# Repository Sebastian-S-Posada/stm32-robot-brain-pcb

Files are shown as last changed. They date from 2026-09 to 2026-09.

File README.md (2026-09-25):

# STM32 Robot Brain PCB

A custom controller board for a small mobile robot, designed in KiCad. It's built around an **STM32F103RCT6** microcontroller and brings together motor drive, sensor, Bluetooth, and programming connections on one 2-layer board.

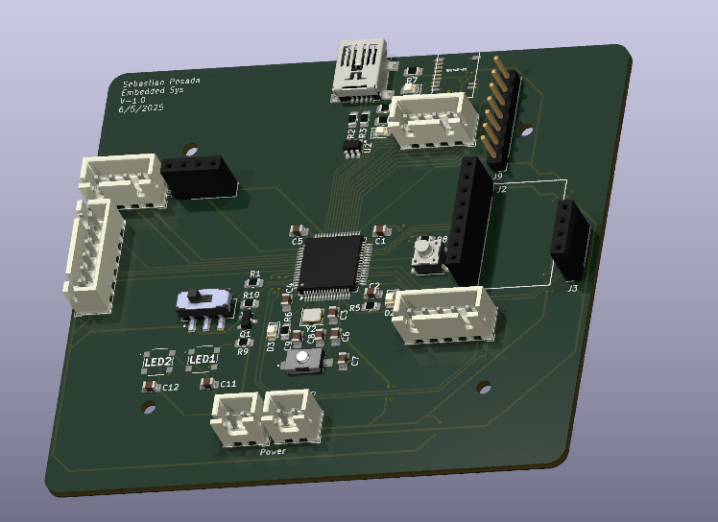
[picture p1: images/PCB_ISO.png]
3D render of the board


## Features

- **MCU:** STM32F103RCT6 (ARM Cortex-M3, LQFP-64) with a 16 MHz crystal
- **Bluetooth:** MDBT42T-AT module (nRF52-based BLE)
- **USB:** Mini-B connector with USBLC6-2SC6 ESD protection and a resettable PTC fuse
- **Programming:** SWD header, plus BOOT and RESET switches
- **Sensor headers:** MPU6050 IMU and ultrasonic distance sensor
- **Robot I/O:** motor driver, Hall-effect encoders, track sensor, PS2 controller, and UART (JST-XH connectors)
- **Power:** separate 5 V and 3.3 V inputs, with power indicator LEDs
- **User I/O:** user button, user LED, Bluetooth status LED, and two RGB LEDs
- **Level shifting:** BSS138 MOSFET

## Images

| Top | Bottom |
|---|---|
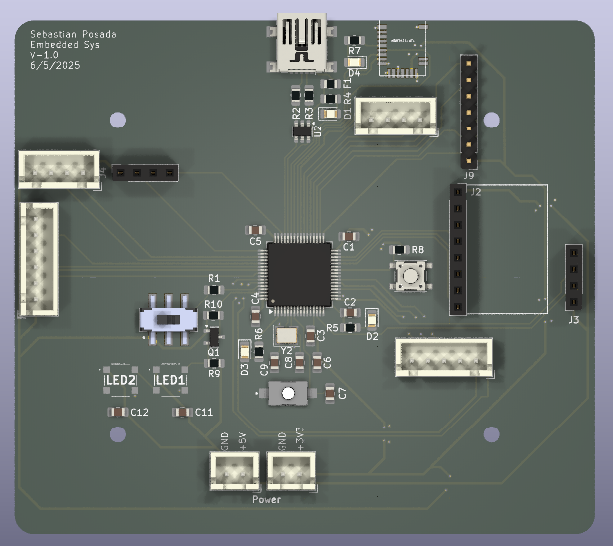
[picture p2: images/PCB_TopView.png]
Top view
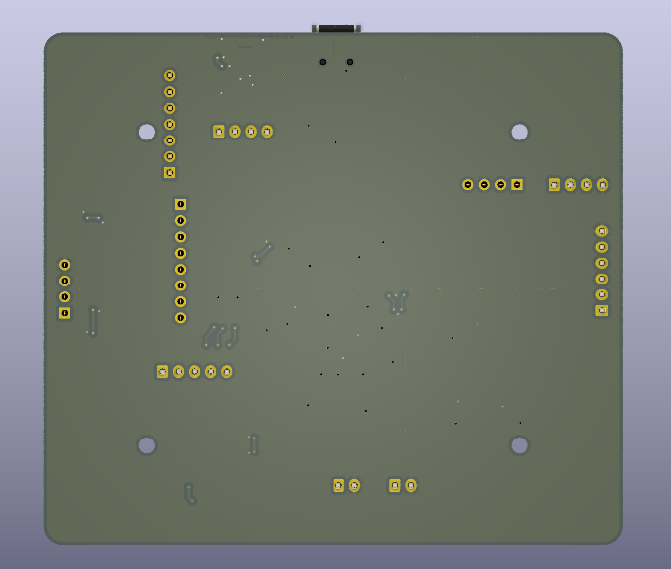
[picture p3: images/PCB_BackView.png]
Back view
|  |  |

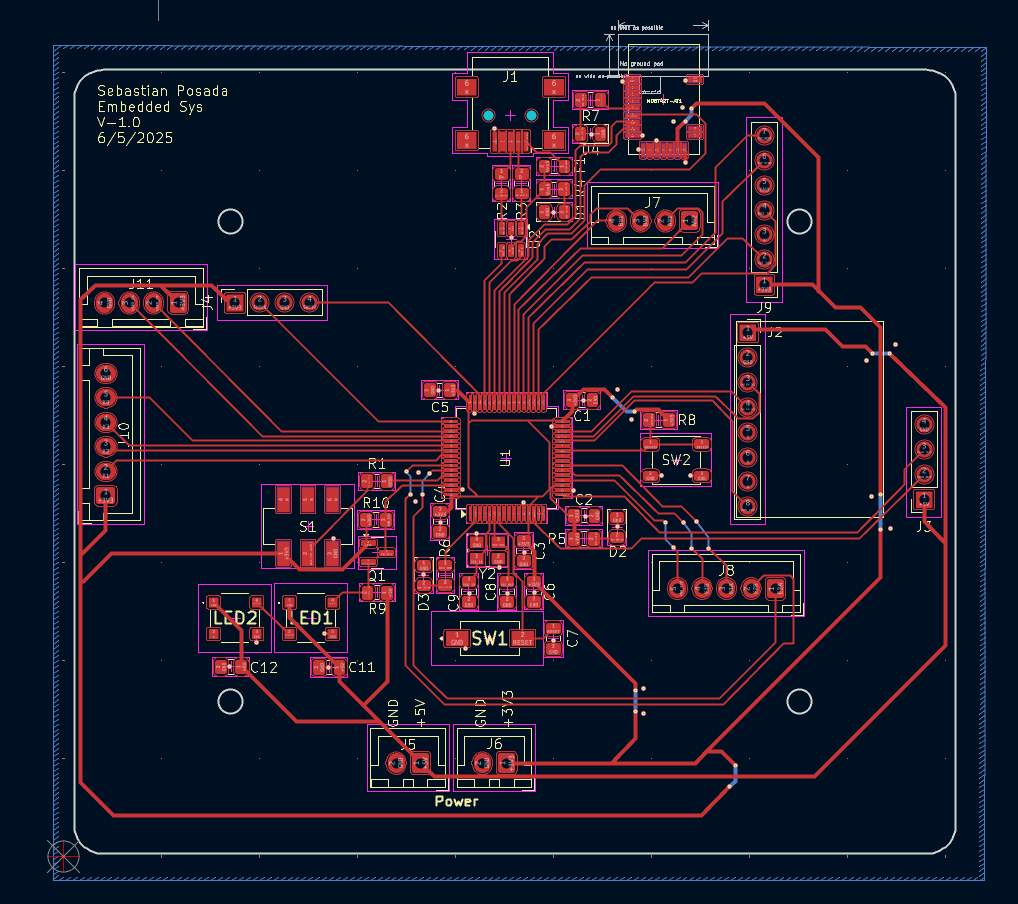
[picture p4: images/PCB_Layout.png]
Routed layout


The full schematic is in [images/schematic.pdf](images/schematic.pdf).

## Repository layout

```
hardware/
  *.kicad_pro / .kicad_sch / .kicad_pcb   KiCad project, schematic, and layout
  motor_controller.kicad_sch               Motor controller sub-sheet
  components/                              Custom symbols, footprints, and 3D models
  BOM/                                     Bill of materials (CSV)
  gerber/                                  Fabrication files (Gerbers and drill files)
images/                                    Renders and schematic PDF
```

## Opening the project

1. Install [KiCad](https://www.kicad.org/) (version 8 or newer).
2. Open `hardware/2025_04_STM32F103_RobotBrain.kicad_pro`.

To order boards, zip the contents of `hardware/gerber/` and upload them to a PCB fab such as JLCPCB or PCBWay.

## Context

Designed for an embedded systems course (ENCE 4231), spring 2025.

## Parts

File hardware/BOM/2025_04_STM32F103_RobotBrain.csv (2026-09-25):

Reference | Qty | Value | DNP | Footprint | Mfr #P | Mouser | Unit Price($)
C1,C2,C3,C4,C5,C11,C12 | 7 | 0.1uF |  | Capacitor_SMD:C_0805_2012Metric_Pad1.18x1.45mm_HandSolder | KAM21BR71H104JT | https://www.mouser.com/ProductDetail/KYOCERA-AVX/KAM21BR71H104JT | 0.20
C6 | 1 | 10uF |  | Capacitor_SMD:C_0805_2012Metric_Pad1.18x1.45mm_HandSolder | LMK212ABJ106KG-T | https://www.mouser.com/ProductDetail/TAIYO-YUDEN/LMK212ABJ106KG-T?qs=vF%252B8ahGVileYw6h2RCH8zg%3D%3D | 0.11
C7 | 1 | 0.01uF |  | Capacitor_SMD:C_0805_2012Metric_Pad1.18x1.45mm_HandSolder | KAF21BR72A103JT | https://www.mouser.com/ProductDetail/KYOCERA-AVX/KAF21BR72A103JT | 0.10
C8,C9 | 2 | 22pF |  | Capacitor_SMD:C_0805_2012Metric_Pad1.18x1.45mm_HandSolder | 0805ZA220JAT2A | https://www.mouser.com/ProductDetail/KYOCERA-AVX/0805ZA220JAT2A?qs=qVfB0%2FDaMDayn2JkoZWS9w%3D%3D | 0.21
D1 | 1 | USB_PWR_LED |  | LED_SMD:LED_0805_2012Metric_Pad1.15x1.40mm_HandSolder | 150080VS75000 | https://www.mouser.com/ProductDetail/Wurth-Elektronik/150080VS75000 | 0.19
D2 | 1 | uP_PWR_LED |  | LED_SMD:LED_0805_2012Metric_Pad1.15x1.40mm_HandSolder | 150080VS75000 | https://www.mouser.com/ProductDetail/Wurth-Elektronik/150080VS75000 | 0.19
D3 | 1 | USER_LED |  | LED_SMD:LED_0805_2012Metric_Pad1.15x1.40mm_HandSolder | 150080RS75000 | https://www.mouser.com/ProductDetail/Wurth-Elektronik/150080RS75000 | 0.19
D4 | 1 | BL_IND_LED |  | LED_SMD:LED_0805_2012Metric_Pad1.15x1.40mm_HandSolder | 150080VS75000 | https://www.mouser.com/ProductDetail/Wurth-Elektronik/150080VS75000 | 0.19
F1 | 1 | PTCSMD |  | Fuse:Fuse_0805_2012Metric_Pad1.15x1.40mm_HandSolder | 0ZCK0050AF2E | https://www.mouser.com/ProductDetail/Bel-Fuse/0ZCK0050AF2E?qs=jyPKP7YLNfA3woHzbzsK%2FQ%3D%3D | 0.32
J1 | 1 | USB_B_Mini |  | Connector_USB:USB_Mini-B_Lumberg_2486_01_Horizontal | UJ2-MBH-4-SMT-TR | https://www.mouser.com/ProductDetail/Same-Sky/UJ2-MBH-4-SMT-TR?qs=5mqXD9RfOg1Zr%252BwuyT2Oxw%3D%3D | 0.81
J2 | 1 | CONN_MPU6050 |  | Connector_PinSocket_2.54mm:PinSocket_1x08_P2.54mm_Vertical
J3 | 1 | CONN_ULTRA |  | Connector_PinSocket_2.54mm:PinSocket_1x04_P2.54mm_Vertical
J4 | 1 | CONN_SWD |  | Connector_PinSocket_2.54mm:PinSocket_1x04_P2.54mm_Vertical
J5 | 1 | CONN_5V |  | Connector_JST:JST_XH_B2B-XH-A_1x02_P2.50mm_Vertical
J6 | 1 | CONN_3V3 |  | Connector_JST:JST_XH_B2B-XH-A_1x02_P2.50mm_Vertical
J7 | 1 | CONN_DRIVE |  | Connector_JST:JST_XH_B4B-XH-A_1x04_P2.50mm_Vertical
J8 | 1 | CONN_HAL |  | Connector_JST:JST_XH_B5B-XH-A_1x05_P2.50mm_Vertical
J9 | 1 | CONN_PS2 |  | Connector_PinHeader_2.54mm:PinHeader_1x07_P2.54mm_Vertical
J10 | 1 | CONN_TRACK |  | Connector_JST:JST_XH_B6B-XH-A_1x06_P2.50mm_Vertical
J11 | 1 | CONN_UART |  | Connector_JST:JST_XH_B4B-XH-A_1x04_P2.50mm_Vertical
LED1,LED2 | 2 | IN-PI55TATPRPGPB |  | RGB_LED:INPI55TATPRPGPB | IN-PI55TATPRPGPB | https://www.mouser.com/ProductDetail/Inolux/IN-PI55TATPRPGPB | 0.55
MDBT42T-AT1 | 1 | MDBT42T-AT |  | MDBT42T-AT:MDBT42T
Q1 | 1 | BSS138 |  | Package_TO_SOT_SMD:SOT-23 | BSS138 | https://www.mouser.com/ProductDetail/onsemi-Fairchild/BSS138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 | 0.27
R1,R4,R5,R6,R7,R8,R9,R10 | 8 | 10k |  | Resistor_SMD:R_0805_2012Metric_Pad1.20x1.40mm_HandSolder | RK73B2ATTE103J | https://www.mouser.com/ProductDetail/KOA-Speer/RK73B2ATTE103J?qs=I90P2AZw0BqeB%252B5wjce35A%3D%3D | 0.11
R2,R3 | 2 | 22 |  | Resistor_SMD:R_0805_2012Metric_Pad1.20x1.40mm_HandSolder | RC0805FR-7W22RL | https://www.mouser.com/ProductDetail/YAGEO/RC0805FR-7W22RL?qs=tggtontpCXP%252BlWTvsYhmYQ%3D%3D | 0.11
S1 | 1 | JS202011SCQN |  | SW_uP_Boot:SW_uP_Boot | JS202011SCQN | https://www.mouser.com/ProductDetail/CK/JS202011SCQN?qs=LgMIjt8LuD95JYWxZ7NvZA%3D%3D | 0.74
SW1 | 1 | SW_uP_Reset |  | SW_uP_Reset:SW_uP_Reset | 434121025816 | https://www.mouser.com/ProductDetail/Wurth-Elektronik/434121025816?qs=wr8lucFkNMWyfcUAFbmtRw%3D%3D | 0.58
SW2 | 1 | SW_USER |  | Button_Switch_SMD:SW_SPST_PTS647_Sx50 | TL3305BF100QG | https://www.mouser.com/ProductDetail/E-Switch/TL3305BF100QG?qs=IKkN%2F947nfDIPwqPQja%252BvQ%3D%3D | 0.17
U1 | 1 | STM32F103RCTx |  | Package_QFP:LQFP-64_10x10mm_P0.5mm | STM32F103RCT6 | https://www.mouser.com/ProductDetail/STMicroelectronics/STM32F103RCT6?qs=%252BB84zevwoRA6TYzZIgOIoA%3D%3D | 8.08
U2 | 1 | USBLC6-2SC6 |  | Package_TO_SOT_SMD:SOT-23-6 | USBLC6-2SC6 | https://www.mouser.com/ProductDetail/STMicroelectronics/USBLC6-2SC6?qs=po45yt2pPpu%2FhNIlwQdTlg%3D%3D | 0.36
Y2 | 1 | 16MHz |  | Crystal:Crystal_SMD_Abracon_ABM8G-4Pin_3.2x2.5mm | ABM8-16.000MHZ-D1X-T | https://www.mouser.com/ProductDetail/ABRACON/ABM8-16.000MHZ-D1X-T?qs=vLWxofP3U2w30ayrUAlCvg%3D%3D | 0.43

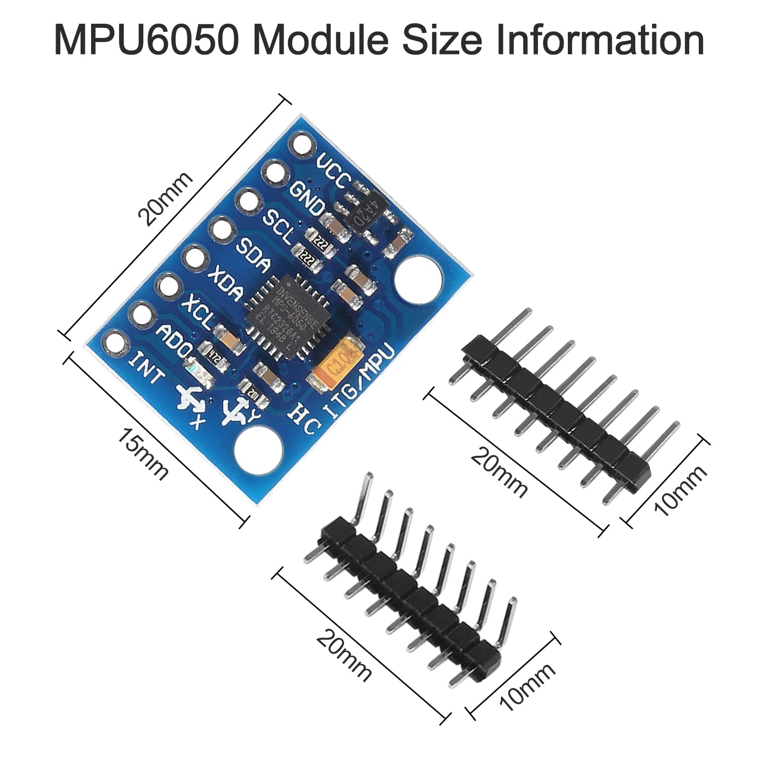
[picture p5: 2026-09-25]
hardware/components/MPU6050/imu_dimensions.jpg

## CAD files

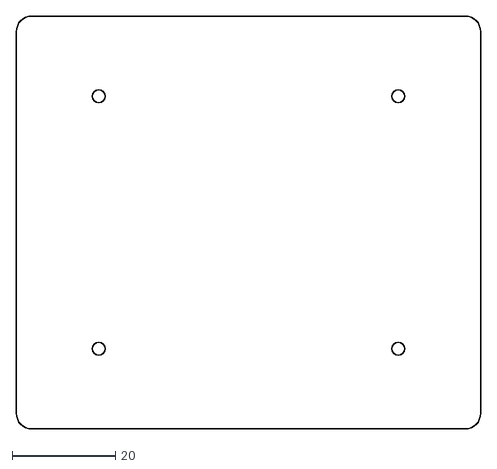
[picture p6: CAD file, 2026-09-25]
hardware/board_layout.dxf
90.0 x 80.0

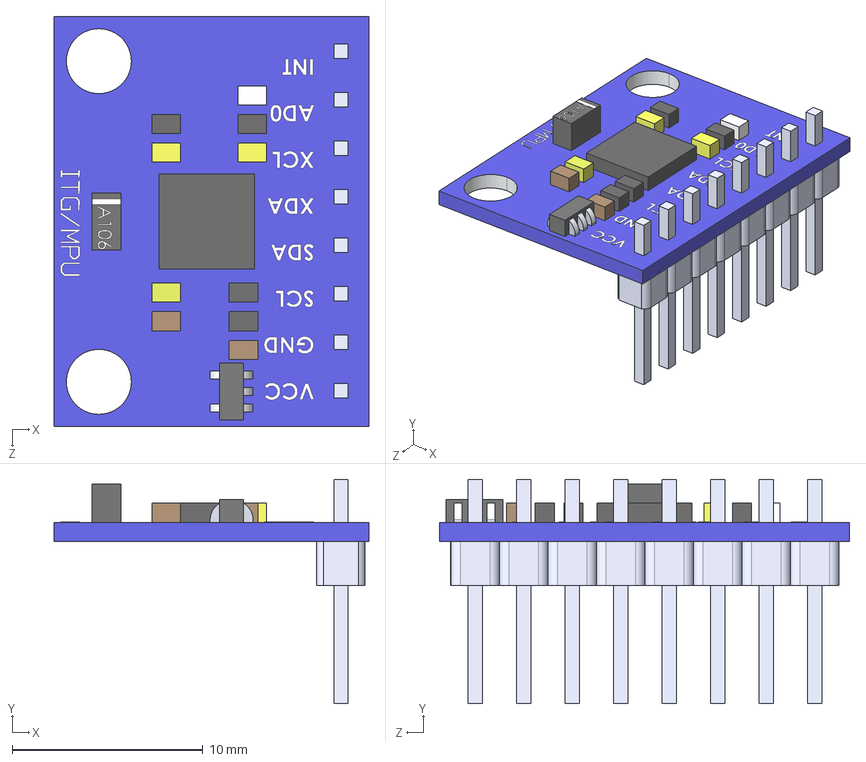
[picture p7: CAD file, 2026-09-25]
hardware/components/MPU6050/ITG-MPU.STEP
16.5 x 11.8 x 21.5 mm
8 Header-Pin
Placa_Base

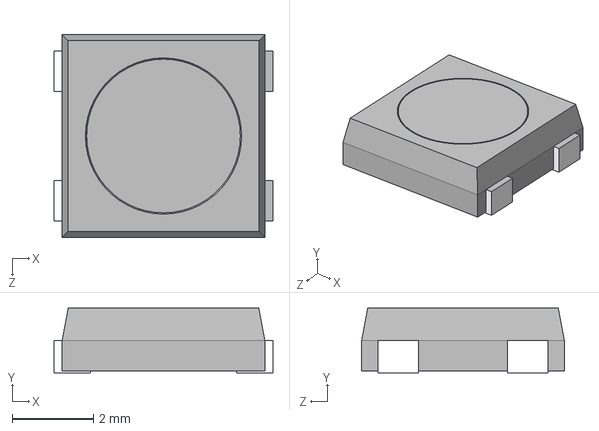
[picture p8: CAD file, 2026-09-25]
hardware/components/RGB_LED/step/RGB_LED.stp
5.40 x 1.60 x 5.00 mm

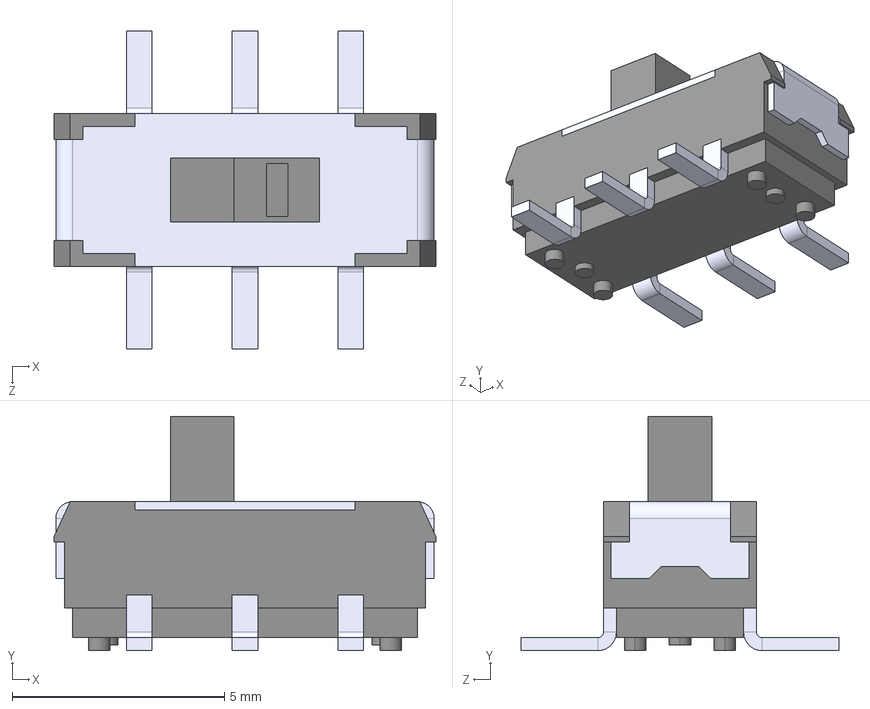
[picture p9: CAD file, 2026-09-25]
hardware/components/SW_uP_Boot/step/SW_uP_Boot.step
8.99 x 5.51 x 7.49 mm

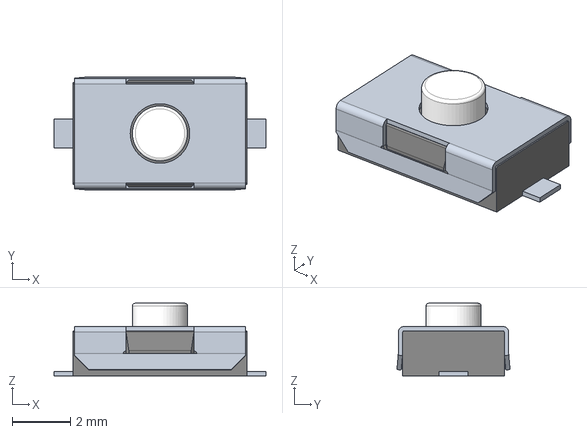
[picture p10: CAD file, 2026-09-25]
hardware/components/SW_uP_Reset/step/SW_uP_Reset.stp
7.30 x 3.90 x 2.50 mm

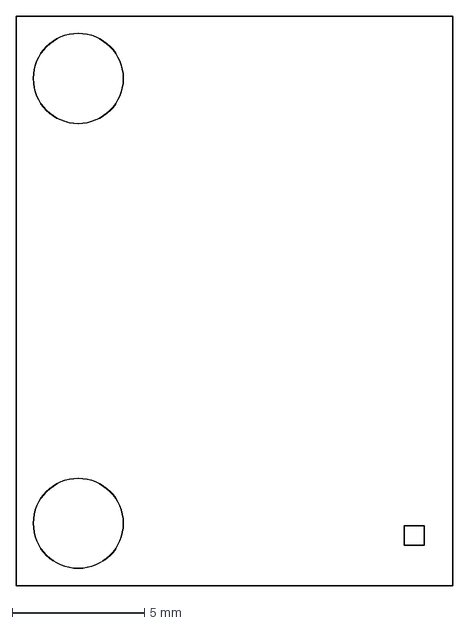
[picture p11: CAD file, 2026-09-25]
hardware/components/MPU6050/MPU6050_PCB_Profile_.dxf
16.5 x 21.5 mm

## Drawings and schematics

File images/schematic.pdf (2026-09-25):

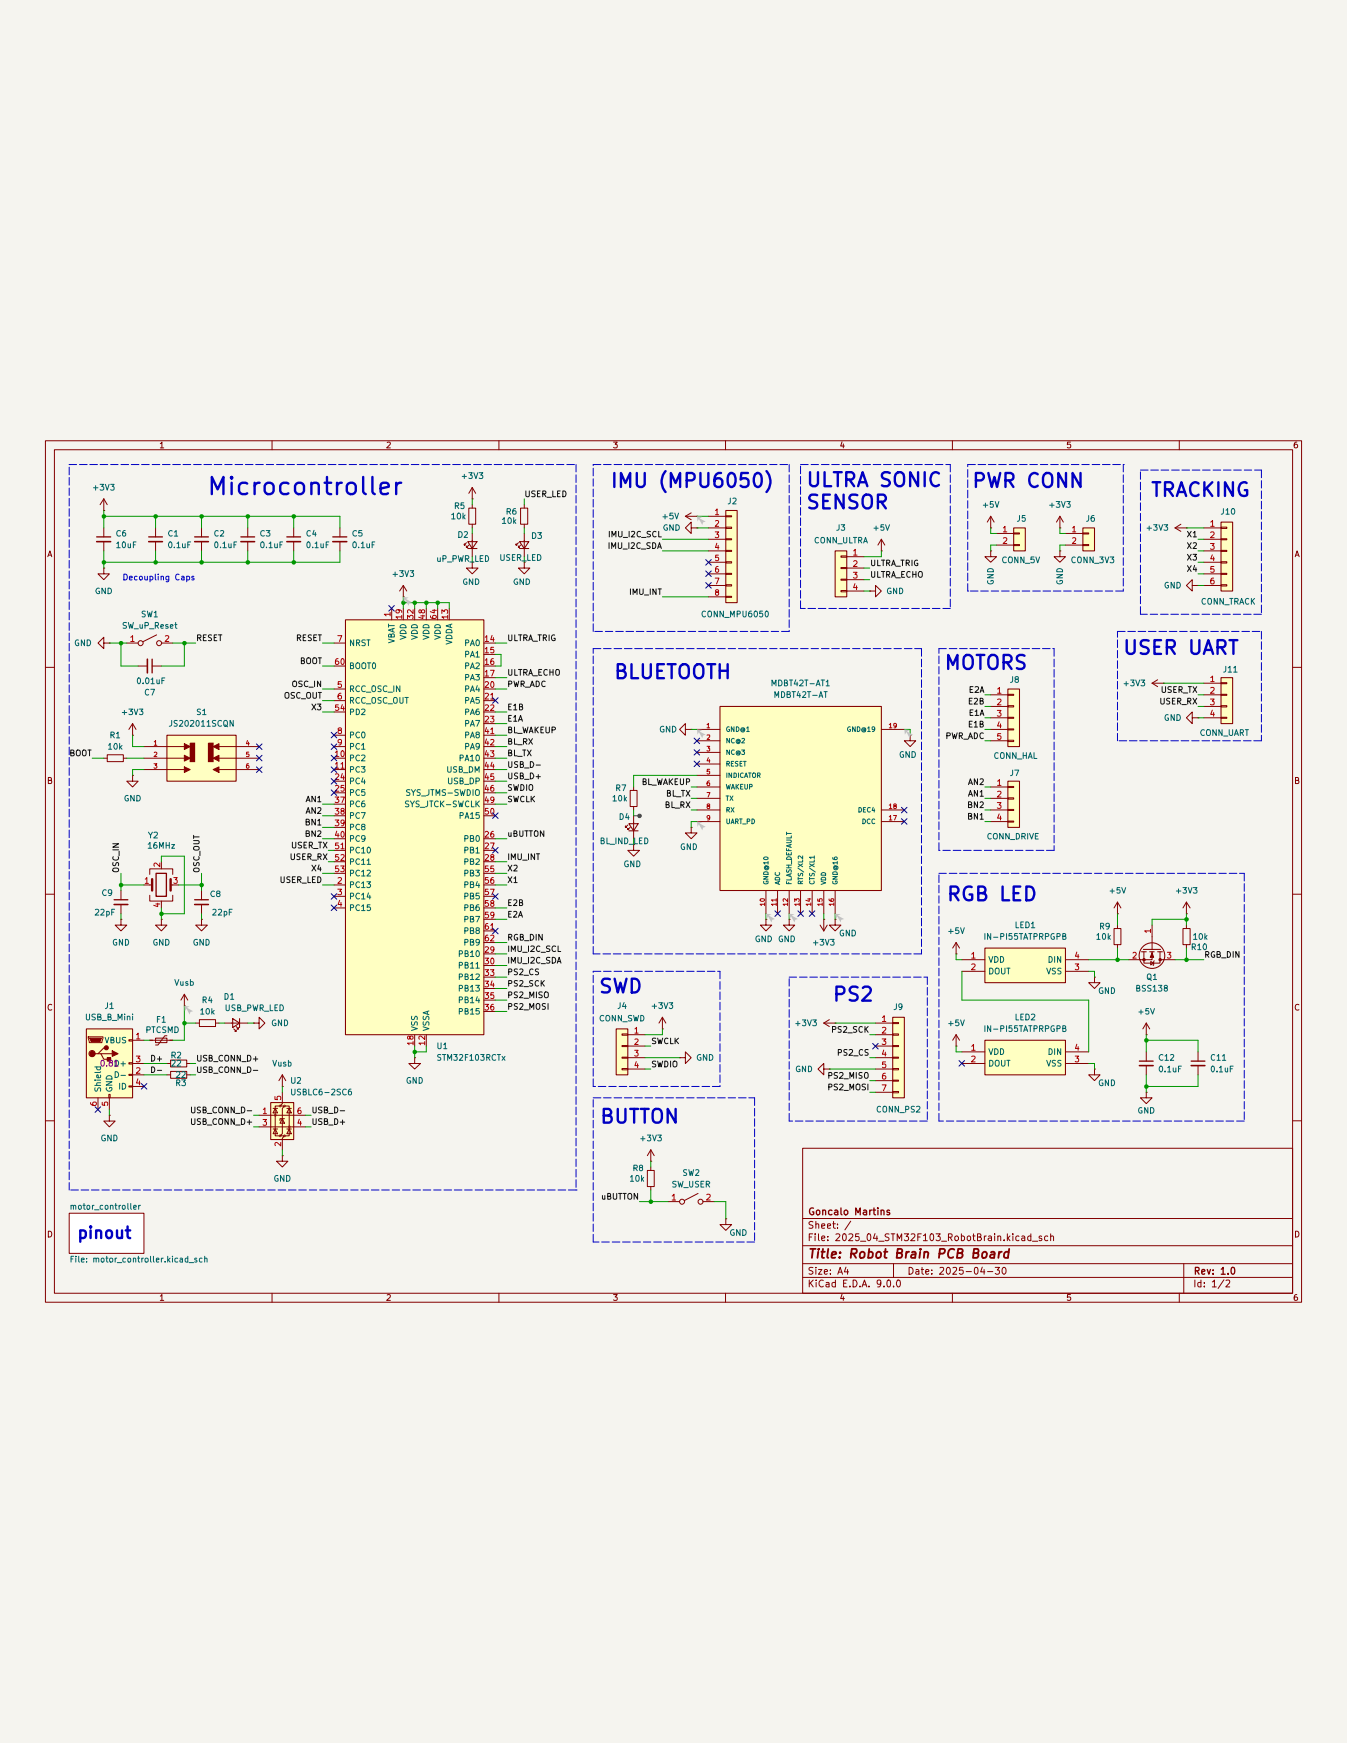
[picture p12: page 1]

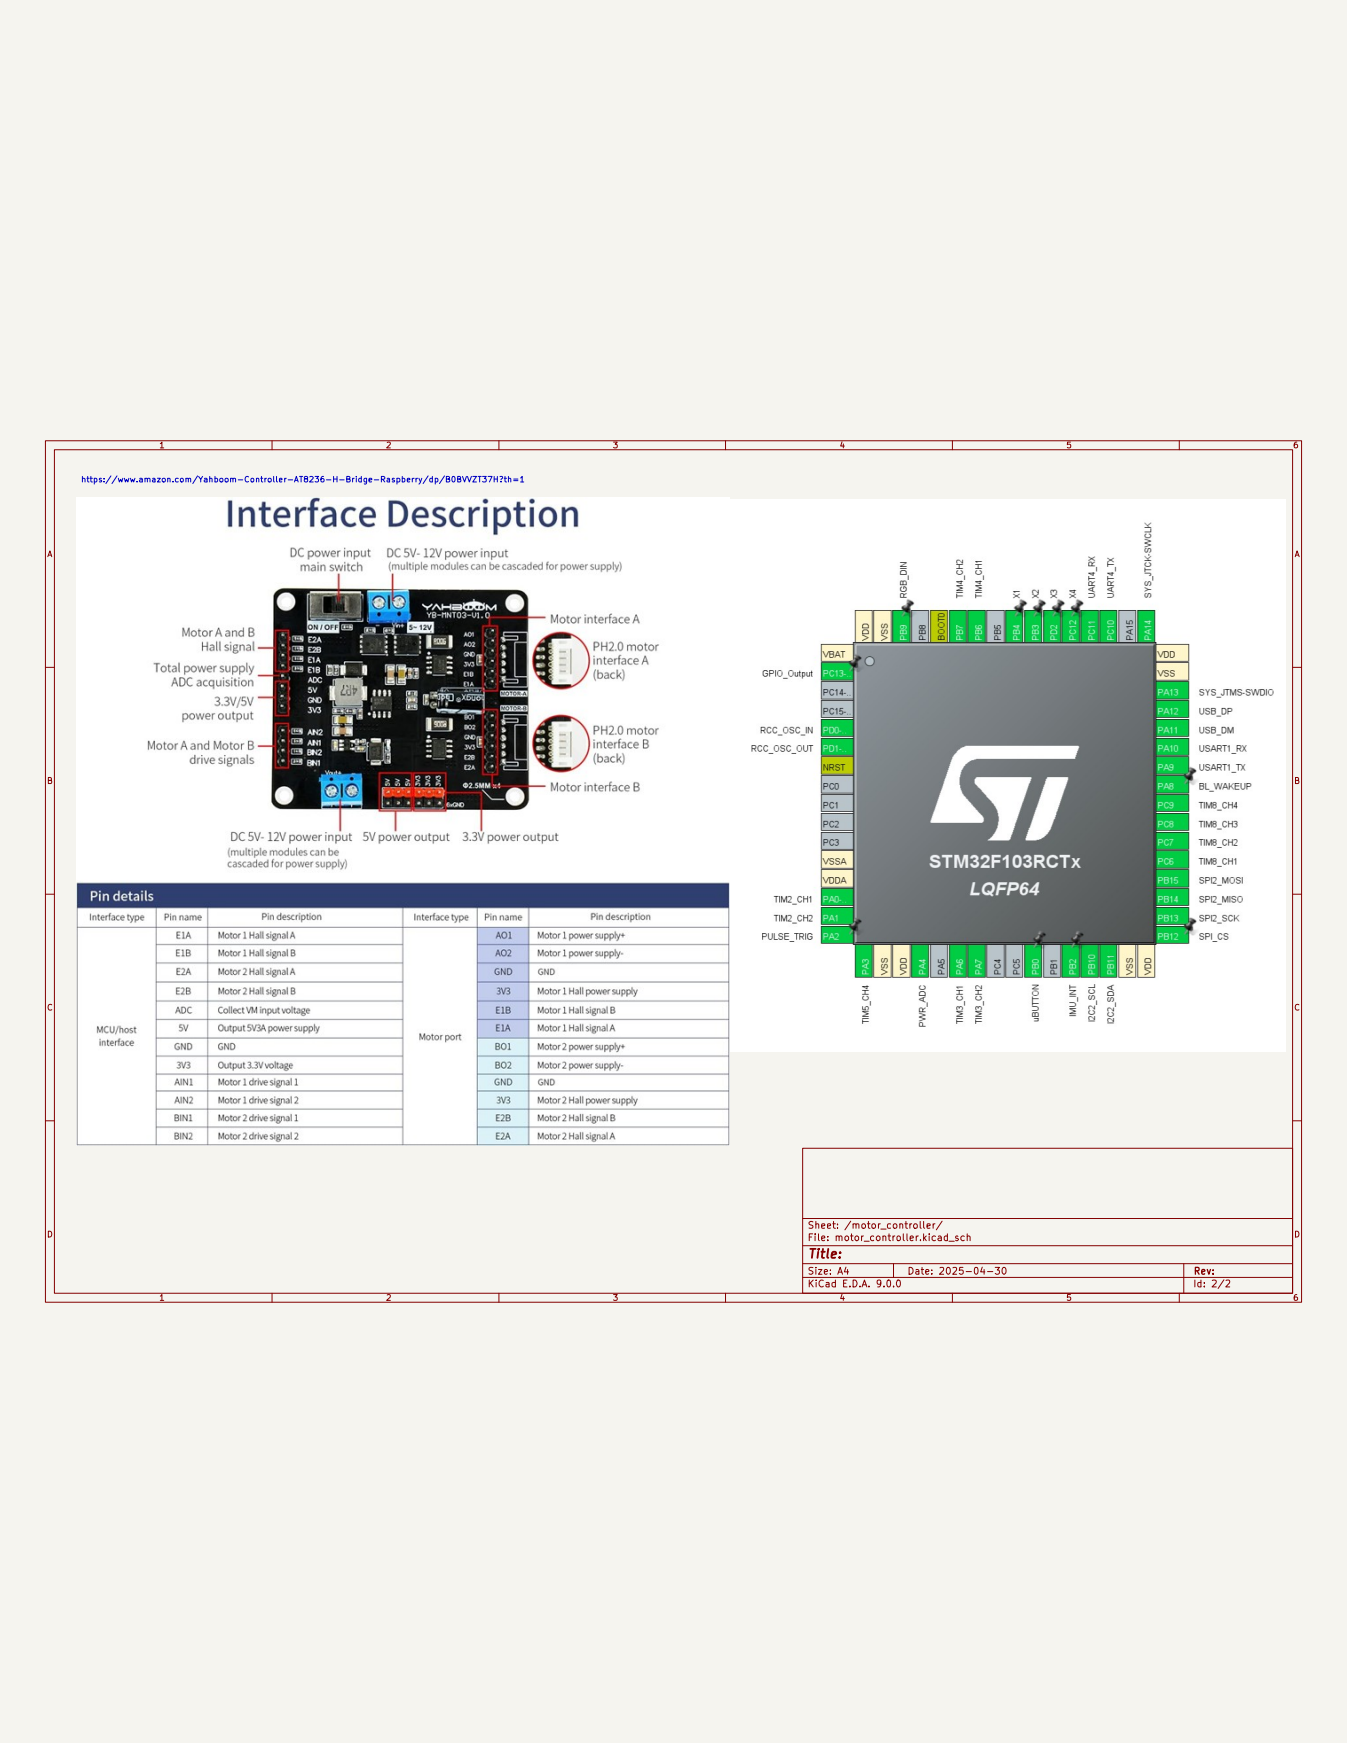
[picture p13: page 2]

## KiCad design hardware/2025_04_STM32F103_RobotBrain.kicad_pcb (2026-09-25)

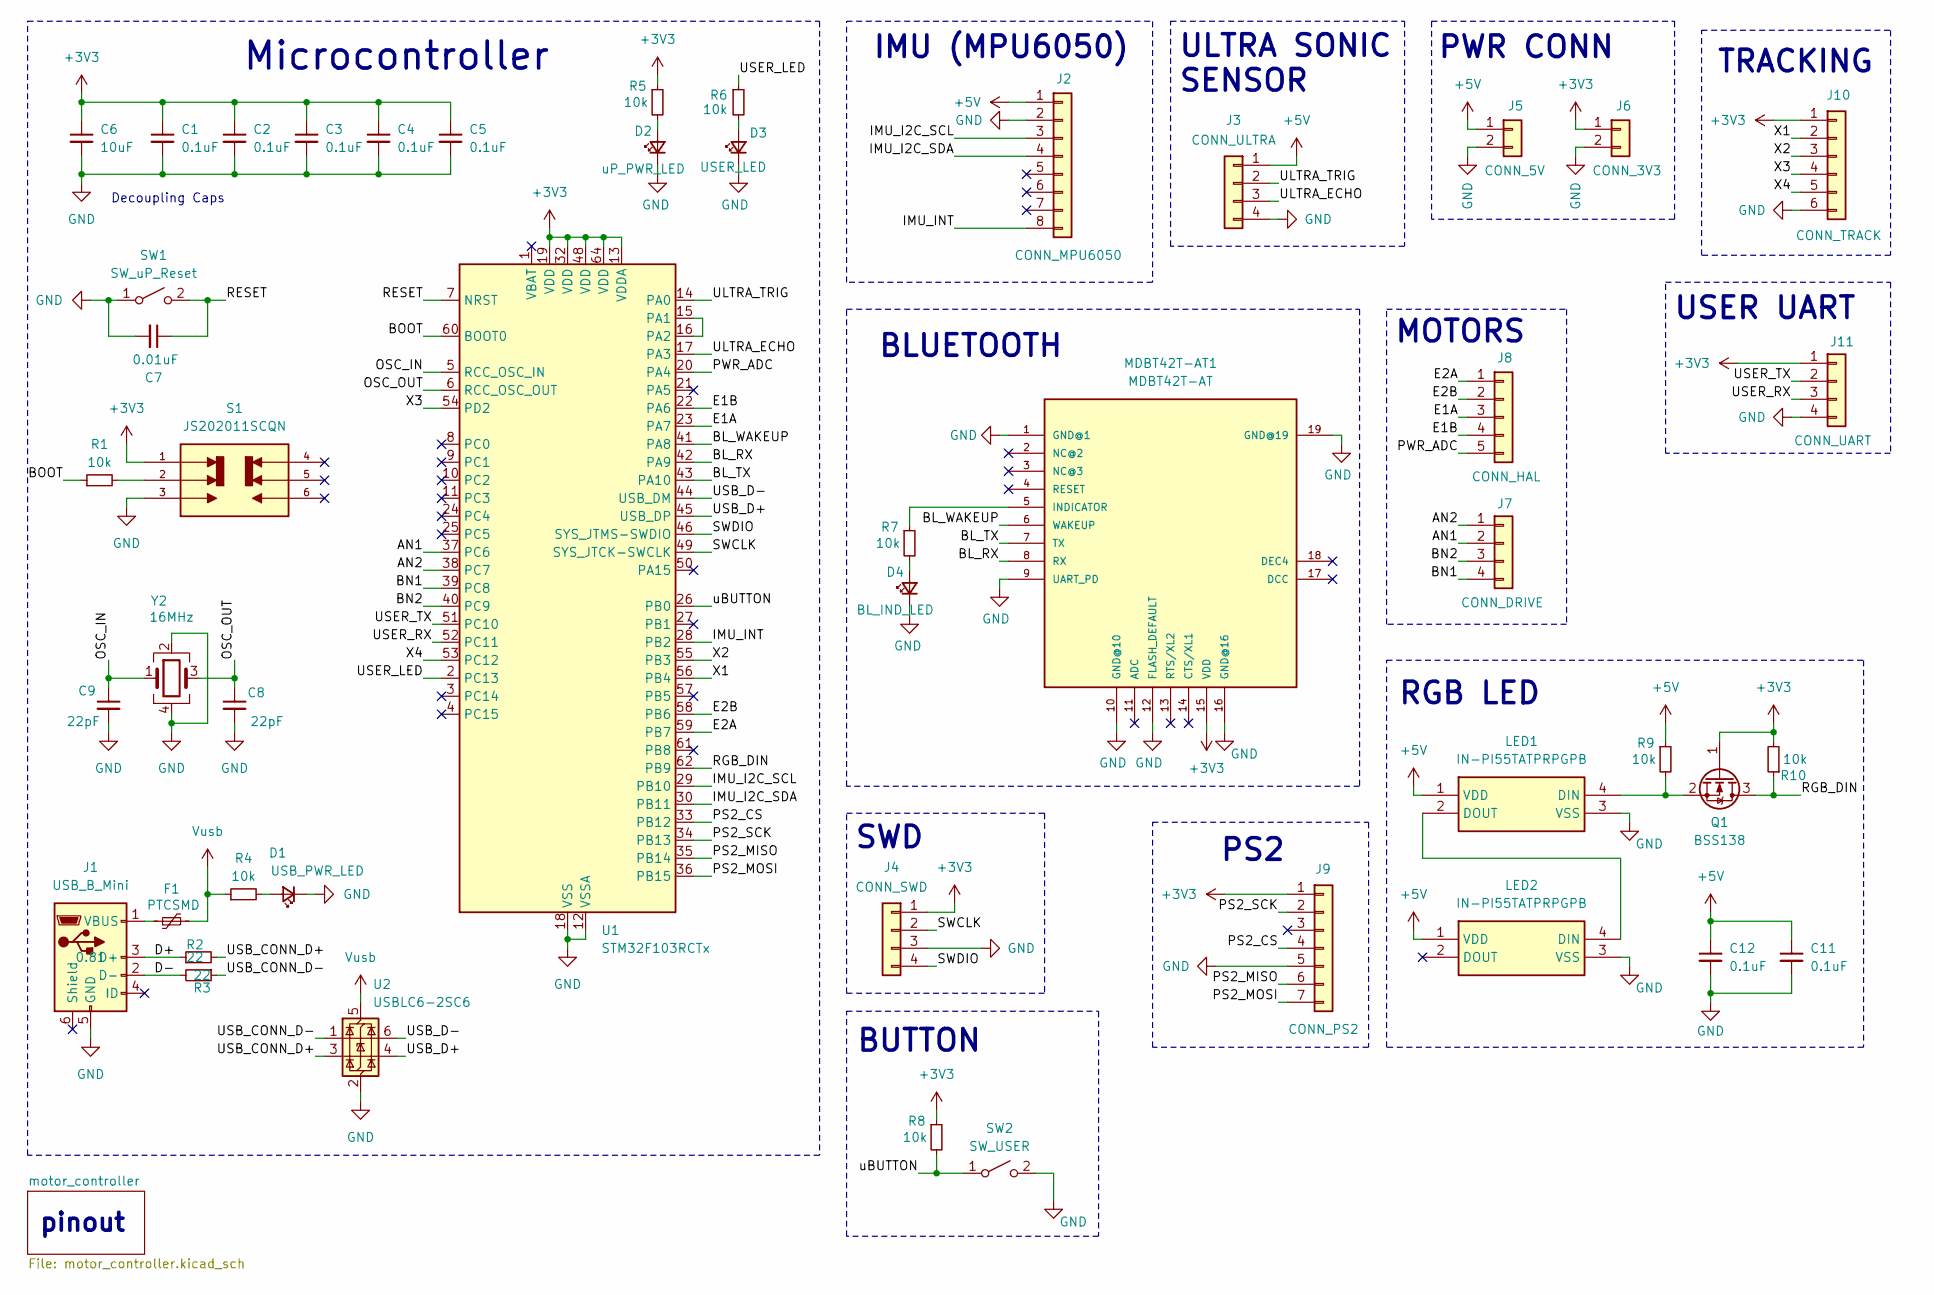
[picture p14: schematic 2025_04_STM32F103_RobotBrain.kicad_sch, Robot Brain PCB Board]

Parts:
C1, C2, C3, C4, C5, C11, C12: 0.1uF; C_0805_2012Metric_Pad1.18x1.45mm_HandSolder; Mfr #P KAM21BR71H104JT
C6: 10uF; C_0805_2012Metric_Pad1.18x1.45mm_HandSolder; Mfr #P LMK212ABJ106KG-T
C7: 0.01uF; C_0805_2012Metric_Pad1.18x1.45mm_HandSolder; Mfr #P KAF21BR72A103JT
C8, C9: 22pF; C_0805_2012Metric_Pad1.18x1.45mm_HandSolder; Mfr #P 0805ZA220JAT2A
D1: USB_PWR_LED; LED_0805_2012Metric_Pad1.15x1.40mm_HandSolder; Mfr #P 150080VS75000
D2: uP_PWR_LED; LED_0805_2012Metric_Pad1.15x1.40mm_HandSolder; Mfr #P 150080VS75000
D3: USER_LED; LED_0805_2012Metric_Pad1.15x1.40mm_HandSolder; Mfr #P 150080RS75000
D4: BL_IND_LED; LED_0805_2012Metric_Pad1.15x1.40mm_HandSolder; Mfr #P 150080VS75000
F1: PTCSMD; Fuse_0805_2012Metric_Pad1.15x1.40mm_HandSolder; Mfr #P 0ZCK0050AF2E
J1: USB_B_Mini; USB_Mini-B_Lumberg_2486_01_Horizontal; Mfr #P UJ2-MBH-4-SMT-TR
J2: CONN_MPU6050; PinSocket_1x08_P2.54mm_Vertical
J3: CONN_ULTRA; PinSocket_1x04_P2.54mm_Vertical
J4: CONN_SWD; PinSocket_1x04_P2.54mm_Vertical
J5: CONN_5V; JST_XH_B2B-XH-A_1x02_P2.50mm_Vertical
J6: CONN_3V3; JST_XH_B2B-XH-A_1x02_P2.50mm_Vertical
J7: CONN_DRIVE; JST_XH_B4B-XH-A_1x04_P2.50mm_Vertical
J8: CONN_HAL; JST_XH_B5B-XH-A_1x05_P2.50mm_Vertical
J9: CONN_PS2; PinHeader_1x07_P2.54mm_Vertical
J10: CONN_TRACK; JST_XH_B6B-XH-A_1x06_P2.50mm_Vertical
J11: CONN_UART; JST_XH_B4B-XH-A_1x04_P2.50mm_Vertical
LED1, LED2: IN-PI55TATPRPGPB; INPI55TATPRPGPB; Manufacturer_Part_Number IN-PI55TATPRPGPB; Mouser Part Number 743-IN-PI55TATPRPGPB
MDBT42T-AT1: MDBT42T-AT; MDBT42T
Q1: BSS138; SOT-23; Mfr #P BSS138
R1, R4, R5, R6, R7, R8, R9, R10: 10k; R_0805_2012Metric_Pad1.20x1.40mm_HandSolder; Mfr #P RK73B2ATTE103J
R2, R3: 22; R_0805_2012Metric_Pad1.20x1.40mm_HandSolder; Mfr #P RC0805FR-7W22RL
S1: JS202011SCQN; SW_uP_Boot; PARTREV 26 May 22
SW1: SW_uP_Reset; Mfr #P 434121025816
SW2: SW_USER; SW_SPST_PTS647_Sx50; Mfr #P TL3305BF100QG
U1: STM32F103RCTx; LQFP-64_10x10mm_P0.5mm; Mfr #P STM32F103RCT6
U2: USBLC6-2SC6; SOT-23-6; Mfr #P USBLC6-2SC6
Y2: 16MHz; Crystal_SMD_Abracon_ABM8G-4Pin_3.2x2.5mm; Mfr #P ABM8-16.000MHZ-D1X-T

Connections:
+3V3: C1.1, C2.1, C3.1, C4.1, C5.1, C6.1, J4.1, J6.1, J9.1, J10.1, J11.1, MDBT42T-AT1.15 (VDD), Q1.1 (G), R5.1, R8.1, R10.2, S1.1, U1.13 (VDDA), U1.19 (VDD), U1.32 (VDD), U1.48 (VDD), U1.64 (VDD)
+5V: C11.1, C12.1, J2.1, J3.1, J5.1, LED1.1 (VDD), LED2.1 (VDD), R9.1
/AN1: J7.2, U1.37 (PC6)
/AN2: J7.1, U1.38 (PC7)
/BL_RX: MDBT42T-AT1.8 (RX), U1.42 (PA9)
/BL_TX: MDBT42T-AT1.7 (TX), U1.43 (PA10)
/BL_WAKEUP: MDBT42T-AT1.6 (WAKEUP), U1.41 (PA8)
/BN1: J7.4, U1.39 (PC8)
/BN2: J7.3, U1.40 (PC9)
/BOOT: R1.1, U1.60 (BOOT0)
/D+: J1.3 (D+), R2.1
/D-: J1.2 (D-), R3.2
/E1A: J8.3, U1.23 (PA7)
/E1B: J8.4, U1.22 (PA6)
/E2A: J8.1, U1.59 (PB7)
/E2B: J8.2, U1.58 (PB6)
/IMU_I2C_SCL: J2.3, U1.29 (PB10)
/IMU_I2C_SDA: J2.4, U1.30 (PB11)
/IMU_INT: J2.8, U1.28 (PB2)
/OSC_IN: C9.1, U1.5 (RCC_OSC_IN), Y2.1
/OSC_OUT: C8.1, U1.6 (RCC_OSC_OUT), Y2.3
/PS2_CS: J9.4, U1.33 (PB12)
/PS2_MISO: J9.6, U1.35 (PB14)
/PS2_MOSI: J9.7, U1.36 (PB15)
/PS2_SCK: J9.2, U1.34 (PB13)
/PWR_ADC: J8.5, U1.20 (PA4)
/RESET: C7.1, SW1.2 (B), U1.7 (NRST)
/RGB_DIN: Q1.3 (D), R10.1, U1.62 (PB9)
/SWCLK: J4.2, U1.49 (SYS_JTCK-SWCLK)
/SWDIO: J4.4, U1.46 (SYS_JTMS-SWDIO)
/ULTRA_ECHO: J3.3, U1.17 (PA3)
/ULTRA_TRIG: J3.2, U1.14 (PA0)
/USB_CONN_D+: R2.2, U2.3 (I/O2)
/USB_CONN_D-: R3.1, U2.1 (I/O1)
/USB_D+: U1.45 (USB_DP), U2.4 (I/O2)
/USB_D-: U1.44 (USB_DM), U2.6 (I/O1)
/USER_LED: R6.1, U1.2 (PC13)
/USER_RX: J11.3, U1.52 (PC11)
/USER_TX: J11.2, U1.51 (PC10)
/X1: J10.2, U1.56 (PB4)
/X2: J10.3, U1.55 (PB3)
/X3: J10.4, U1.54 (PD2)
/X4: J10.5, U1.53 (PC12)
/uBUTTON: R8.2, SW2.1 (A), U1.26 (PB0)
GND: C1.2, C2.2, C3.2, C4.2, C5.2, C6.2, C7.2, C8.2, C9.2, C11.2, C12.2, D1.1 (K), D2.1 (K), D3.1 (K), D4.1 (K), J1.5 (GND), J2.2, J3.4, J4.3, J5.2, J6.2, J9.5, J10.6, J11.4, LED1.3 (VSS), LED2.3 (VSS), MDBT42T-AT1.1 (GND@1), MDBT42T-AT1.9 (UART_PD), MDBT42T-AT1.10 (GND@10), MDBT42T-AT1.12 (FLASH_DEFAULT), MDBT42T-AT1.16 (GND@16), MDBT42T-AT1.19 (GND@19), S1.3, SW1.1 (A), SW2.2 (B), U1.12 (VSSA), U1.18 (VSS), U1.31 (VSS), U1.47 (VSS), U1.63 (VSS), U2.2 (GND), Y2.2, Y2.4
unnamed: D1.2 (A), R4.2
unnamed: D2.2 (A), R5.2
unnamed: D3.2 (A), R6.2
unnamed: D4.2 (A), R7.2
unnamed: F1.1, J1.1 (VBUS)
unnamed: LED1.4 (DIN), Q1.2 (S), R9.2
unnamed: LED1.2 (DOUT), LED2.4 (DIN)
unnamed: MDBT42T-AT1.5 (INDICATOR), R7.1
unnamed: R1.2, S1.2
unnamed: U1.15 (PA1), U1.16 (PA2)
Vusb: F1.2, R4.1, U2.5 (VBUS)

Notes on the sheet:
PWR CONN
ULTRA SONIC SENSOR
Decoupling Caps
BUTTON
MOTORS
PS2
RGB LED
Microcontroller
TRACKING
pinout
IMU (MPU6050)
SWD
USER UART
BLUETOOTH

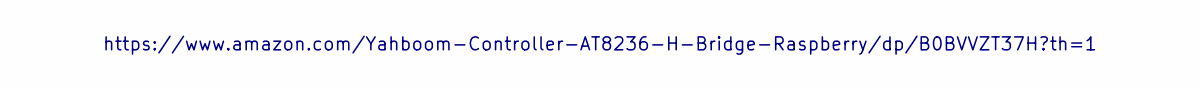
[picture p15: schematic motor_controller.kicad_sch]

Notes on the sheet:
https://www.amazon.com/Yahboom-Controller-AT8236-H-Bridge-Raspberry/dp/B0BVVZT37H?th=1

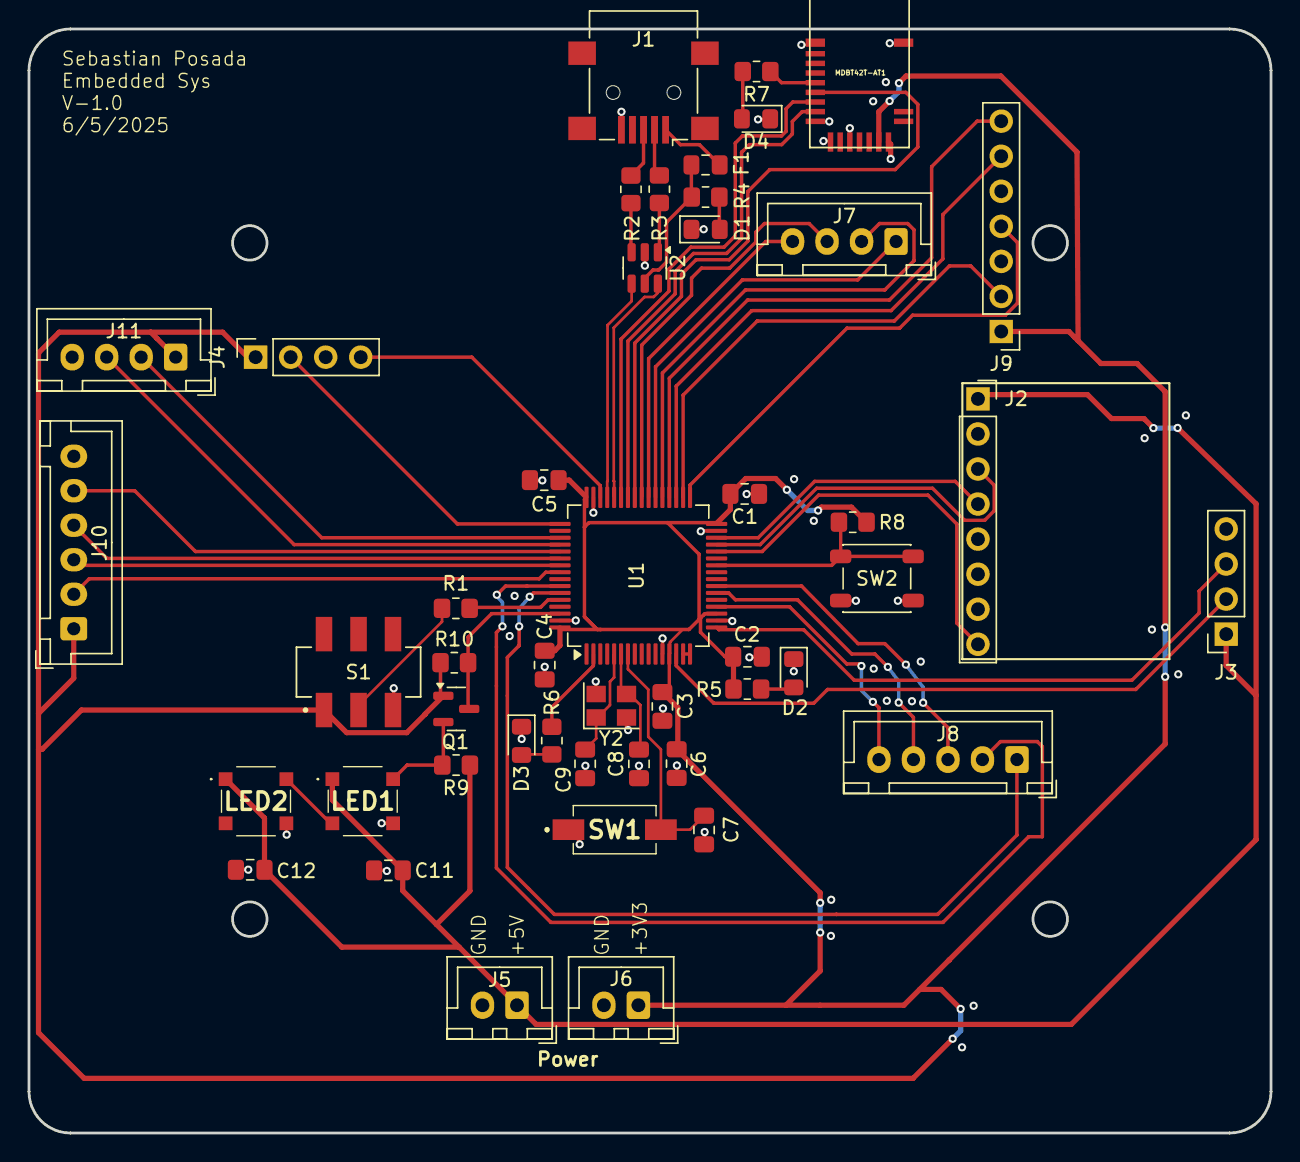
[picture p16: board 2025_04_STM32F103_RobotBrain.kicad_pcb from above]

Board: 2 copper layers, 90.0 x 80.0 mm, 47 parts (0 on the bottom side), 56 nets.
